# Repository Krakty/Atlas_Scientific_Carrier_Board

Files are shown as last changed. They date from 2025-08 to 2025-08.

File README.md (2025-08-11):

# Atlas Scientific EZO Carrier Board

## Overview
A professional carrier board designed for Atlas Scientific EZO circuit boards, featuring full electrical isolation and integrated SMA connectors for reliable sensor connectivity.

Based on the [Atlas Scientific Electrically Isolated EZO Carrier Board Gen 2](https://atlas-scientific.com/carrier-boards/electrically-isolated-ezo-carrier-board-gen-2/), this design provides enhanced isolation and connectivity features for demanding applications.

### Design Improvements
This prototype incorporates several component upgrades from the reference design:
- **SI8600AC-B-ISR digital isolators** for improved signal integrity and isolation performance
- **RFM-0505S power modules** for reliable isolated power delivery
- **1206 package components** for easier hand assembly and prototype testing

## Features
- **4 EZO Circuit Slots**: Supports up to 4 Atlas Scientific EZO circuit boards simultaneously
- **Full Electrical Isolation**: Complete galvanic isolation between each EZO circuit to prevent ground loops and interference
- **Integrated SMA Connectors**: Professional-grade SMA connectors for secure and reliable probe connections
- **Modular Design**: Easy installation and removal of EZO circuits without soldering

## Supported EZO Circuits
This carrier board is compatible with the full range of Atlas Scientific EZO circuits including:
- pH
- ORP (Oxidation-Reduction Potential)
- Dissolved Oxygen
- Conductivity
- Temperature (RTD)
- Flow
- CO2
- Pressure
- Humidity
- And more...

## Technical Specifications
- **Isolation**: Full galvanic isolation between channels
  - **Digital Isolator**: SI8600AC-B-ISR (Silicon Labs) - High-speed digital isolator for I2C/UART signals (4x units)
  - **Power Isolation**: RFM-0505S - Isolated DC/DC converter module (5V to 5V, 4x units)
- **Connectors**: 
  - SMA female connectors (132289) for probe connections (4x)
  - JST XH 4-pin connector for I2C input
  - Pin headers for EZO circuit connections
- **Communication**: I2C/UART pass-through for each isolated channel
- **Power**: Isolated power supply for each EZO circuit
- **Protection**: BVSS138LT1G MOSFETs for level shifting and protection (4x)
- **Component Package**: 1206 series resistors and capacitors for easier prototype assembly and testing
  - 10kΩ pull-up resistors (10x)
  - 1MΩ resistors (8x)
  - 1µF capacitors (8x)
  - 470Ω LED resistor with power indicator

## Applications
- Water quality monitoring systems
- Hydroponics and aquaponics automation
- Industrial process control
- Environmental monitoring stations
- Research and development
- Educational laboratories

## Design Files
This repository contains:
- PCB design files (KiCad)
- Schematic diagrams
- [Bill of Materials (BOM)](Atlas_Scientific_Carrier_Board.csv) - Complete component list with quantities and specifications
- 3D models
- Manufacturing files (Gerbers)

## Safety & Compliance
- Designed with electrical safety in mind
- Full isolation prevents ground loops
- Protected against cross-channel interference
- Industrial-grade components

## License
[License information to be added]

## References & Documentation
- [Atlas Scientific Electrically Isolated EZO Carrier Board Gen 2](https://atlas-scientific.com/carrier-boards/electrically-isolated-ezo-carrier-board-gen-2/) - Original carrier board reference
- [Carrier Board Technical Datasheet (PDF)](https://files.atlas-scientific.com/electrically-isolated-ezo-carrier-board.pdf) - Detailed specifications and wiring diagrams
- [Atlas Scientific EZO Circuit Documentation](https://atlas-scientific.com/circuits/) - Complete EZO circuit specifications
- [Atlas Scientific Support](https://atlas-scientific.com/support/) - Technical support and resources

## Contact
For questions, support, or custom modifications, please open an issue in this repository.

---
*Professional carrier board solution for Atlas Scientific EZO circuits with enhanced isolation and connectivity*

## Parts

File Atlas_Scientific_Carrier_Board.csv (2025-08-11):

Id | Designator | Footprint | Quantity | Designation | Supplier and ref
1 | C7,C5,C3,C1,C8,C6,C4,C2 | C_1206_3216Metric_Pad1.33x1.80mm_HandSolder | 8 | 1uF
2 | PS2,PS4,PS3,PS1 | LIB_RFM-0505S | 4 | RFM-0505S
3 | I2C_Input1 | JST_XH_S4B-XH-A_1x04_P2.50mm_Horizontal | 1 | ~
4 | U3,U4,U2,U1 | LIB_SI8600AD-B-IS | 4 | SI8600AC-B-ISR
5 | R3,R18,R17,R13,R14,R12,R11,R5,R6,R2 | R_1206_3216Metric_Pad1.30x1.75mm_HandSolder | 10 | 10Kohm
6 | TP3,TP4,TP2,TP1 | TestPoint_Loop_D2.54mm_Drill1.5mm_Beaded | 4 | TestPoint
7 | R19 | R_1206_3216Metric_Pad1.30x1.75mm_HandSolder | 1 | 470 Ohm
8 | D1 | LED_1206_3216Metric_Pad1.42x1.75mm_HandSolder | 1 | ~
9 | Q4,Q3,Q2,Q1 | SOT96P237X111-3N | 4 | BVSS138LT1G
10 | R16,R15,R8,R9,R10,R7,R4,R1 | R_1206_3216Metric_Pad1.30x1.75mm_HandSolder | 8 | 1M
11 | J10,J12,J7,J9,J6,J3,J2,J1 | PinHeader_1x03_P2.54mm_Vertical | 8 | Conn_01x03
12 | J11,J8,J5,J4 | LIB_132289 | 4 | 132289

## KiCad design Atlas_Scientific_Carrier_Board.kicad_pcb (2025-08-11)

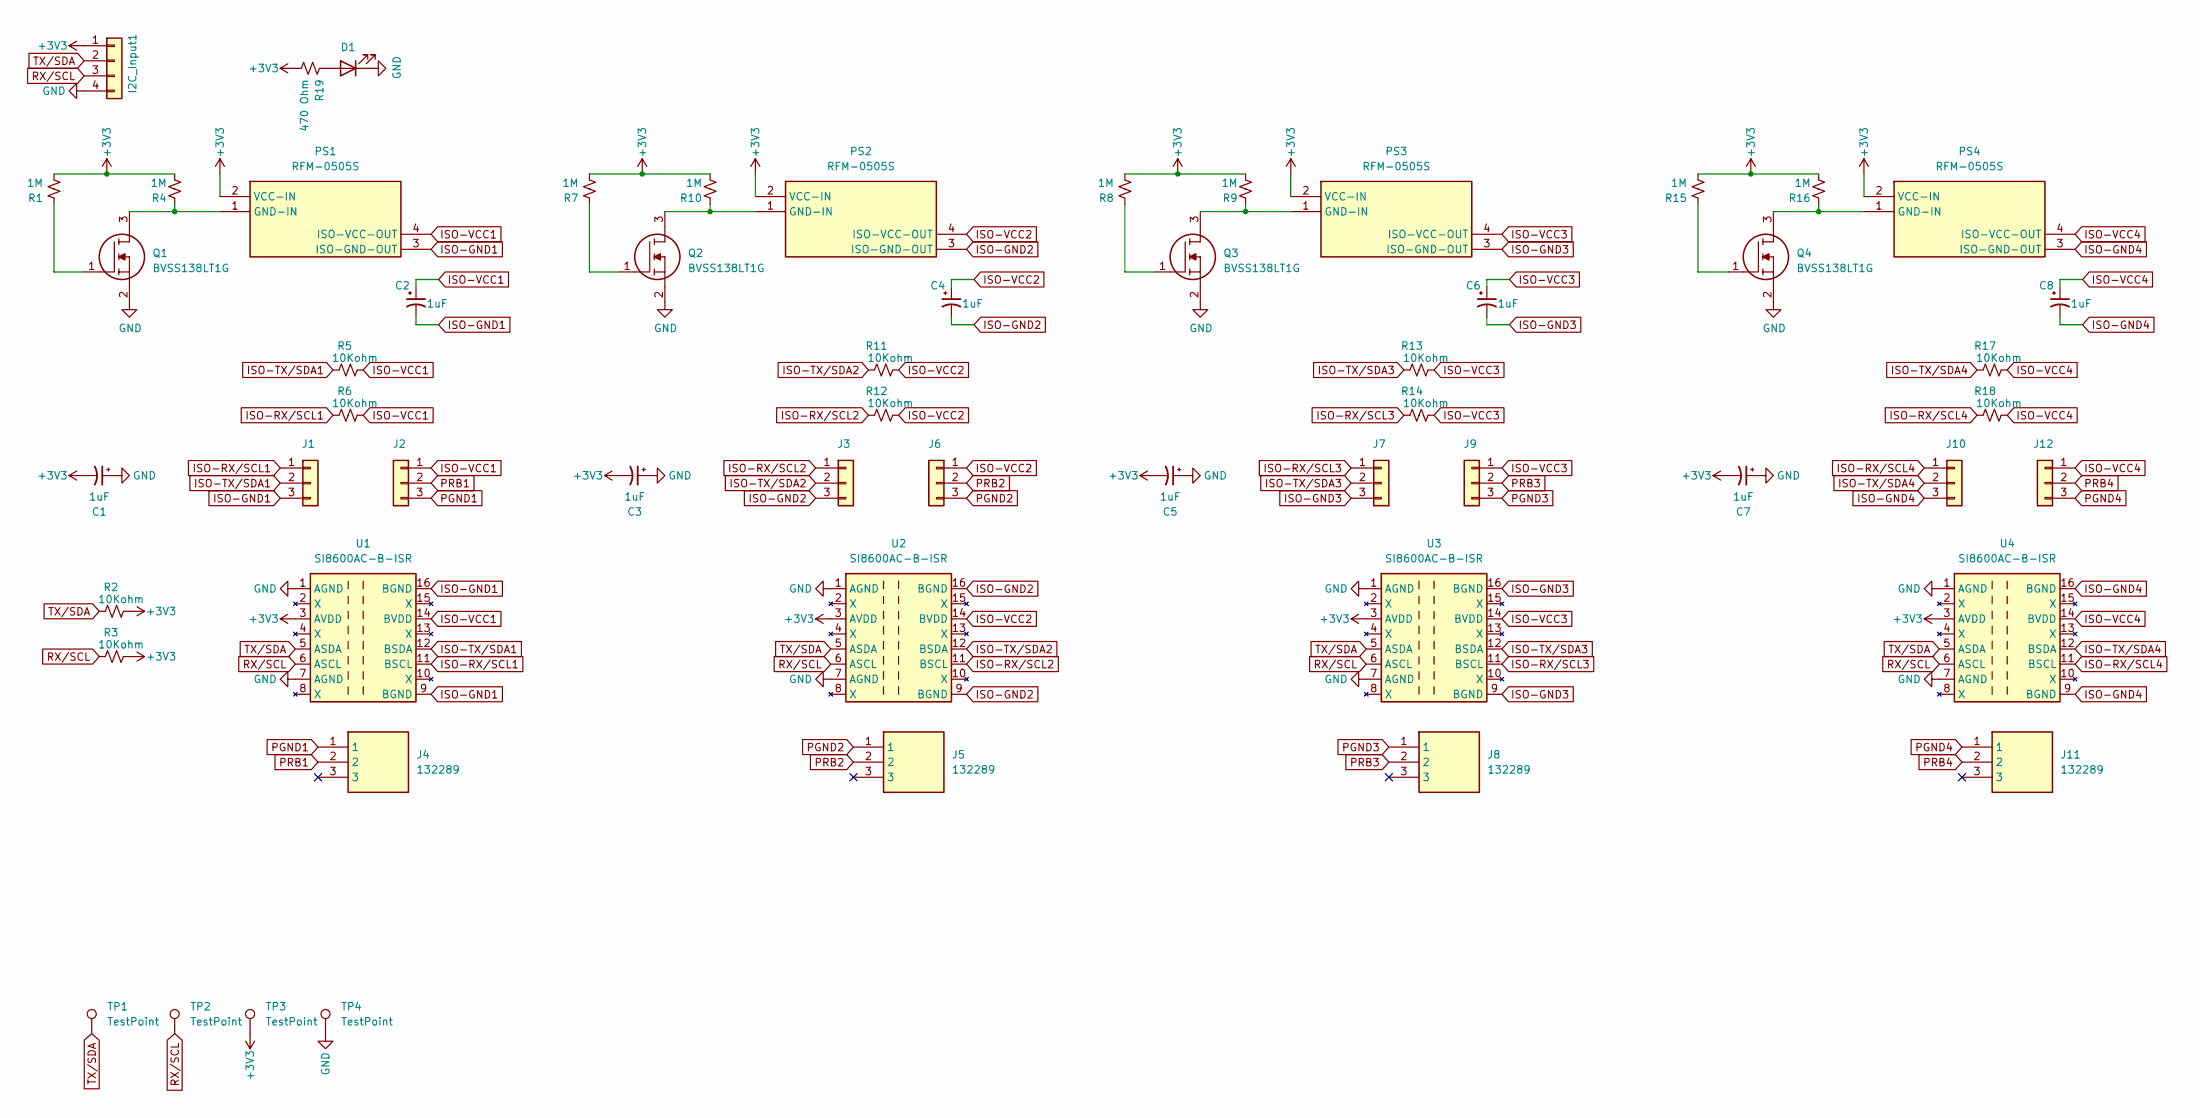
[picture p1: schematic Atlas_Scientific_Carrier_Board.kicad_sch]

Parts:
C1, C2, C3, C4, C5, C6, C7, C8: 1uF; C_1206_3216Metric_Pad1.33x1.80mm_HandSolder
D1: LED_1206_3216Metric_Pad1.42x1.75mm_HandSolder
I2C_Input1: JST_XH_S4B-XH-A_1x04_P2.50mm_Horizontal
J1, J2, J3, J6, J7, J9, J10, J12: Conn_01x03; PinHeader_1x03_P2.54mm_Vertical
J4, J5, J8, J11: 132289; LIB_132289; Mouser Part Number 523-132289
PS1, PS2, PS3, PS4: RFM-0505S; LIB_RFM-0505S; Mouser Part Number 919-RFM-0505S
Q1, Q2, Q3, Q4: BVSS138LT1G; SOT96P237X111-3N; Mouser Part Number 863-BVSS138LT1G
R1, R4, R7, R8, R9, R10, R15, R16: 1M; R_1206_3216Metric_Pad1.30x1.75mm_HandSolder
R2, R3, R5, R6, R11, R12, R13, R14, R17, R18: 10Kohm; R_1206_3216Metric_Pad1.30x1.75mm_HandSolder
R19: 470 Ohm; R_1206_3216Metric_Pad1.30x1.75mm_HandSolder
TP1, TP2, TP3, TP4: TestPoint; TestPoint_Loop_D2.54mm_Drill1.5mm_Beaded
U1, U2, U3, U4: SI8600AC-B-ISR; LIB_SI8600AD-B-IS; Part # SI8600AC-B-ISR

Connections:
+3V3: C1.2, C3.2, C5.2, C7.2, I2C_Input1.1, PS1.2 (VCC-IN), PS2.2 (VCC-IN), PS3.2 (VCC-IN), PS4.2 (VCC-IN), R1.2, R2.2, R3.2, R4.2, R7.2, R8.2, R9.2, R10.2, R15.2, R16.2, R19.2, TP3.1, U1.3 (AVDD), U2.3 (AVDD), U3.3 (AVDD), U4.3 (AVDD)
GND: C1.1, C3.1, C5.1, C7.1, D1.1 (K), I2C_Input1.4, Q1.2, Q2.2, Q3.2, Q4.2, TP4.1, U1.1 (AGND), U1.7 (AGND), U2.1 (AGND), U2.7 (AGND), U3.1 (AGND), U3.7 (AGND), U4.1 (AGND), U4.7 (AGND)
ISO-GND1: C2.2, J1.3, PS1.3 (ISO-GND-OUT), U1.9 (BGND), U1.16 (BGND)
ISO-GND2: C4.2, J3.3, PS2.3 (ISO-GND-OUT), U2.9 (BGND), U2.16 (BGND)
ISO-GND3: C6.2, J7.3, PS3.3 (ISO-GND-OUT), U3.9 (BGND), U3.16 (BGND)
ISO-GND4: C8.2, J10.3, PS4.3 (ISO-GND-OUT), U4.9 (BGND), U4.16 (BGND)
ISO-RX/SCL1: J1.1, R6.1, U1.11 (BSCL)
ISO-RX/SCL2: J3.1, R12.1, U2.11 (BSCL)
ISO-RX/SCL3: J7.1, R14.1, U3.11 (BSCL)
ISO-RX/SCL4: J10.1, R18.1, U4.11 (BSCL)
ISO-TX/SDA1: J1.2, R5.1, U1.12 (BSDA)
ISO-TX/SDA2: J3.2, R11.1, U2.12 (BSDA)
ISO-TX/SDA3: J7.2, R13.1, U3.12 (BSDA)
ISO-TX/SDA4: J10.2, R17.1, U4.12 (BSDA)
ISO-VCC1: C2.1, J2.1, PS1.4 (ISO-VCC-OUT), R5.2, R6.2, U1.14 (BVDD)
ISO-VCC2: C4.1, J6.1, PS2.4 (ISO-VCC-OUT), R11.2, R12.2, U2.14 (BVDD)
ISO-VCC3: C6.1, J9.1, PS3.4 (ISO-VCC-OUT), R13.2, R14.2, U3.14 (BVDD)
ISO-VCC4: C8.1, J12.1, PS4.4 (ISO-VCC-OUT), R17.2, R18.2, U4.14 (BVDD)
unnamed: D1.2 (A), R19.1
unnamed: PS1.1 (GND-IN), Q1.3, R4.1
unnamed: PS2.1 (GND-IN), Q2.3, R10.1
unnamed: PS3.1 (GND-IN), Q3.3, R9.1
unnamed: PS4.1 (GND-IN), Q4.3, R16.1
unnamed: Q1.1, R1.1
unnamed: Q2.1, R7.1
unnamed: Q3.1, R8.1
unnamed: Q4.1, R15.1
PGND1: J2.3, J4.1
PGND2: J5.1, J6.3
PGND3: J8.1, J9.3
PGND4: J11.1, J12.3
PRB1: J2.2, J4.2
PRB2: J5.2, J6.2
PRB3: J8.2, J9.2
PRB4: J11.2, J12.2
RX/SCL: I2C_Input1.3, R3.1, TP2.1, U1.6 (ASCL), U2.6 (ASCL), U3.6 (ASCL), U4.6 (ASCL)
TX/SDA: I2C_Input1.2, R2.1, TP1.1, U1.5 (ASDA), U2.5 (ASDA), U3.5 (ASDA), U4.5 (ASDA)

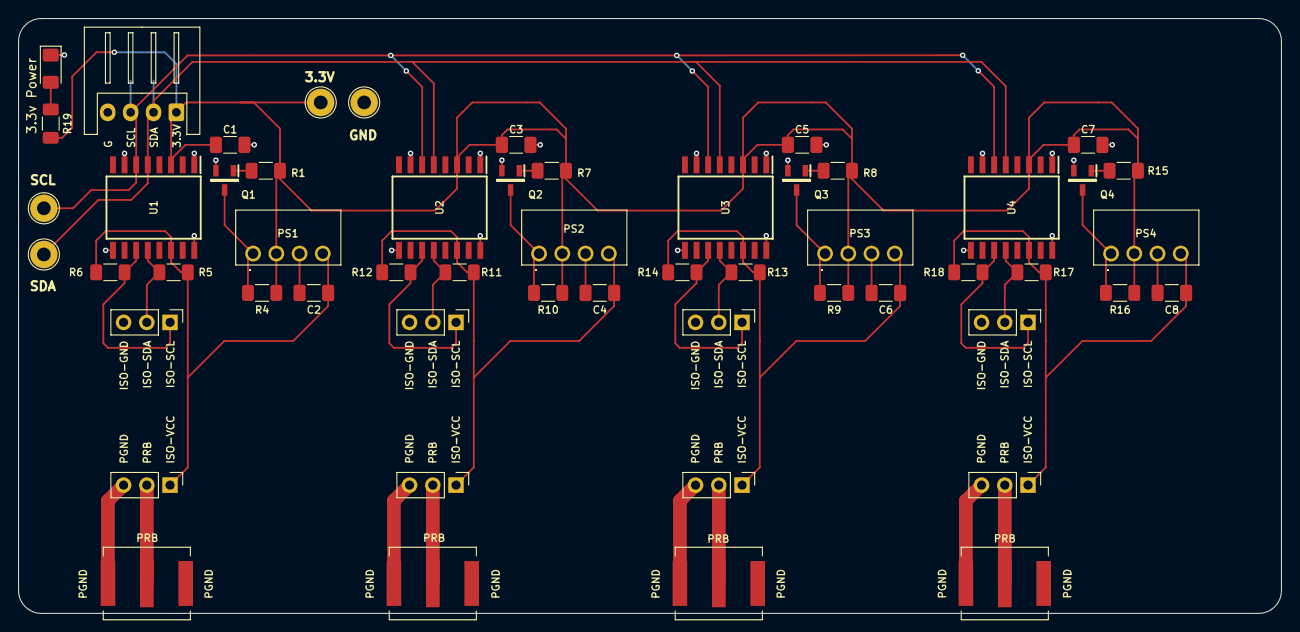
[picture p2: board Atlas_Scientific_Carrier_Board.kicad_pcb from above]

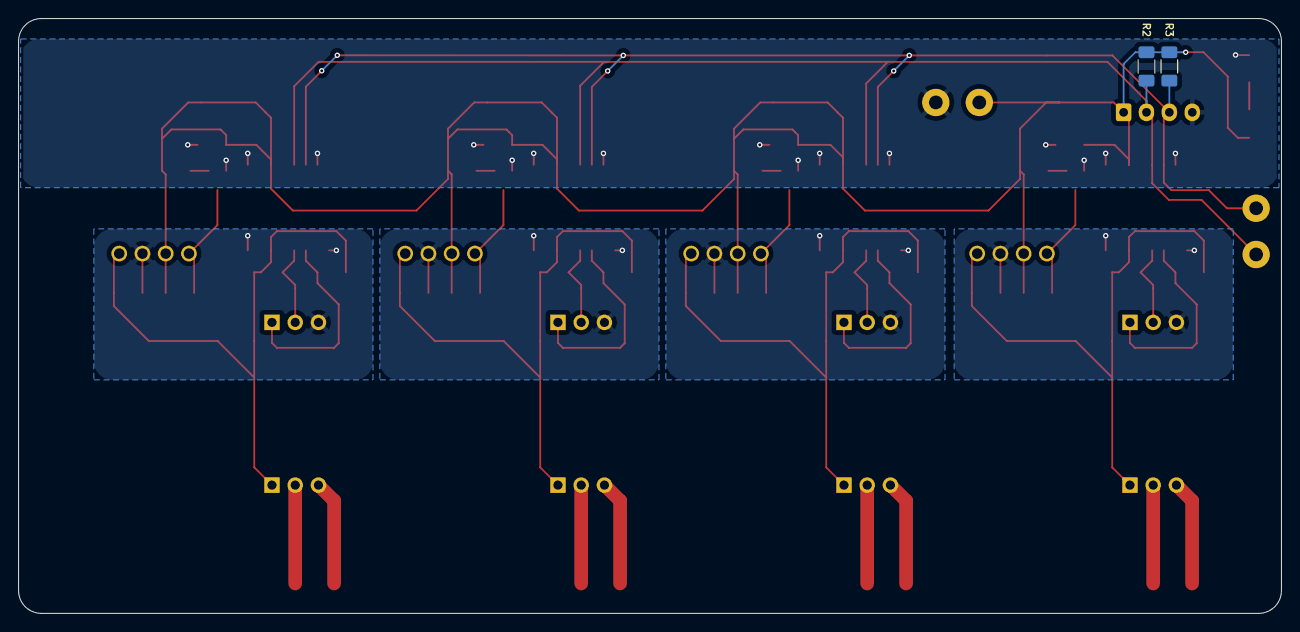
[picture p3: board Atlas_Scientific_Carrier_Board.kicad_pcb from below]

Board: 2 copper layers, 138.0 x 65.0 mm, 57 parts (2 on the bottom side), 37 nets.

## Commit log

2025-08-11 Initial commit: Atlas Scientific EZO Carrier Board
    - Professional carrier board for 4 Atlas Scientific EZO circuits
    - Features full electrical isolation between channels
    - Integrated SMA connectors for reliable sensor connectivity
    - KiCad PCB design files included
    - Comprehensive project documentation in README
    This carrier board provides a robust solution for multi-sensor deployments
    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
    [Atlas_Scientific_Carrier_Board.kicad_pcb, Atlas_Scientific_Carrier_Board.kicad_sch]
2025-08-11 Add Atlas Scientific documentation references
    - Added reference to original Atlas Scientific Electrically Isolated EZO Carrier Board Gen 2
    - Included links to EZO circuit documentation and support resources
    - Clarified that this design is based on Atlas Scientific's carrier board
2025-08-11 Add technical datasheet PDF link
    - Added link to Atlas Scientific carrier board technical datasheet PDF
    - Provides detailed specifications and wiring diagrams for reference
2025-08-11 Document specific component choices for prototype
    - Added SI8600AC-B-ISR digital isolator specification
    - Added RFM-0505S isolated DC/DC converter details
    - Noted use of 1206 series components for easier prototyping
    - Highlighted design improvements from reference board
    These component choices optimize for prototype assembly and testing
    while maintaining full electrical isolation performance.
2025-08-11 Add BOM file and update component specifications
    - Added Bill of Materials CSV file with complete component list
    - Updated README with detailed component specifications from BOM:
    - 4x SI8600AC-B-ISR digital isolators
    - 4x RFM-0505S isolated DC/DC converters
    - 4x SMA connectors (part #132289)
    - 4x BVSS138LT1G MOSFETs for protection
    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
    [Atlas_Scientific_Carrier_Board.csv]
